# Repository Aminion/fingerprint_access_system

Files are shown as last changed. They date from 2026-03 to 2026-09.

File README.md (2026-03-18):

# Fingerprint Access System





## Project Overview

This project implements a complete biometric access control. It handles asynchronous UART communication for fingerprint authentication, ADC measurements for battery diagnostics, and PWM control for physical actuation. The firmware is written entirely in `no_std` Rust, utilizing the Embassy framework for concurrent, event-driven execution without the overhead of a traditional RTOS.

### Core Capabilities
* **Biometric Authentication:** Secure, asynchronous UART communication with a fingerprint module for user enrollment and verification.
* **PWM-Optimized Actuation:** Implementation of a "peak-and-hold" solenoid drive mechanism using Hardware PWM, significantly reducing active power consumption and thermal load.
* **Ratiometric Battery Diagnostics:** A custom ADC measurement strategy utilizing an external TL431 reference to accurately calculate battery capacity, regardless of internal 3.3V rail voltage sag.
* **Zero-State Power Gating:** Physical isolation of analog subsystems (voltage dividers, reference chips) via GPIO-controlled switching, ensuring 0mA draw from these components during system standby.

## Software Stack & Hardware Architecture

### Software
* **Language:** Rust (`no_std`)
* **Framework:** Embassy (Embedded Async)
* **Concurrency Model:** `embassy-executor` for lightweight task scheduling and interrupt management.

### Hardware & Peripherals
* **Microcontroller:** STM32G031K8 (Nucleo-32)
* **Sensor:** GROW R503
* **Power Supply:** 4xAAA NiMH Battery Pack (~4.0V - 6.0V)
* **Peripheral Utilization:**
  * **PWM (Pulse Width Modulation):** Configured to manage the solenoid's current draw, as well as generate user-feedback tones.
  * **ADC (Analog-to-Digital Converter):** Utilizes extended sample timing (`Cycles160_5`) and floating-point calibration math to bypass hardware limitations.
  * **UART (Universal Asynchronous Receiver-Transmitter):** Handles packet-based serial data transfer with the biometric sensor.
  * **GPIO:** Configured for push-pull power switching and standard digital I/O.

## Engineering Challenges Solved

### 1. Solenoid Power Optimization (Peak-and-Hold)
Solenoids require a high initial "pull-in" current to overcome mechanical inertia, but require significantly less current to maintain the unlocked state. Driving a solenoid at 100% duty cycle for the duration of the unlock period wastes battery capacity and generates excess heat.
* **Solution:** The firmware utilizes hardware PWM to drive the actuating transistor. It applies a 100% duty cycle for the initial actuation phase (e.g., 100ms), then instantly drops the duty cycle to a calculated holding percentage (e.g., 30%). This reduces the holding power consumption by up to 70% while keeping the lock disengaged.

### 2. Ratiometric ADC Calibration
On low pin-count STM32 microcontrollers, the analog reference pin (`AREF`) is internally bonded to `VDDA`. Consequently, when the main 3.3V rail sags under load, the ADC reference shifts, causing inaccurate battery readings.
* **Solution:** A TL431 (2.495V) precision external reference was introduced to a standard ADC channel. The firmware samples both the unknown battery voltage and the known TL431 voltage concurrently. By dynamically calculating the deviation of the TL431 reading, the software mathematically reconstructs the true scale of the 3.3V rail, resulting in a highly accurate battery percentage regardless of system load.

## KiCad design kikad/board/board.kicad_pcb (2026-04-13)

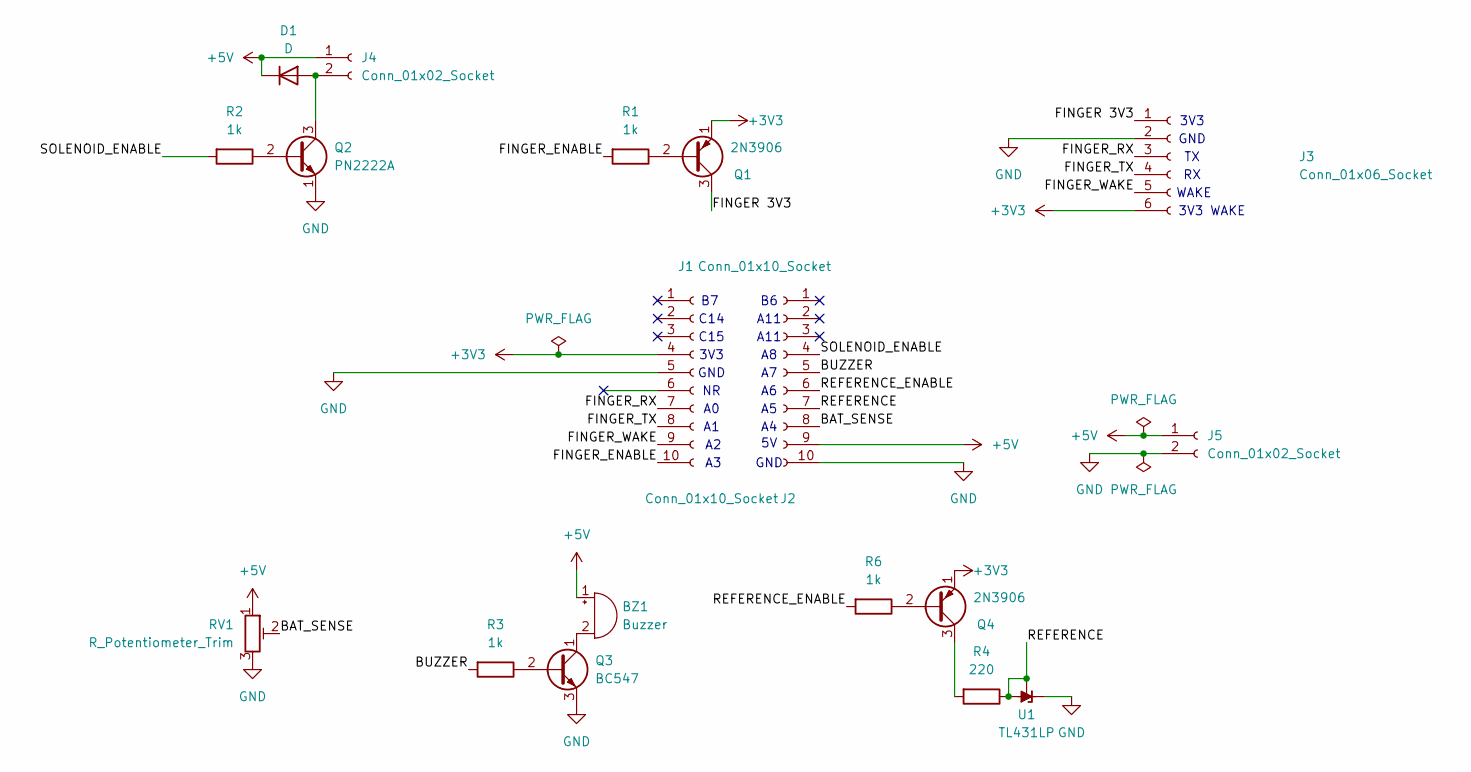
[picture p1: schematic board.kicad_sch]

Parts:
BZ1: Buzzer; Buzzer_12x9.5RM7.6
D1: D; D_DO-41_SOD81_P10.16mm_Horizontal
J1: Conn_01x10_Socket; PinSocket_1x10_P2.54mm_Vertical
J2: Conn_01x10_Socket
J3: Conn_01x06_Socket; JST_XH_B6B-XH-A_1x06_P2.50mm_Vertical
J4, J5: Conn_01x02_Socket; JST_XH_B2B-XH-A_1x02_P2.50mm_Vertical
Q1, Q4: 2N3906; TO-92_Inline_Wide
Q2: PN2222A; TO-92_Inline_Wide
Q3: BC547; TO-92_Inline_Wide
R1, R2, R3, R6: 1k; R_Axial_DIN0207_L6.3mm_D2.5mm_P10.16mm_Horizontal
R4: 220; R_Axial_DIN0207_L6.3mm_D2.5mm_P10.16mm_Horizontal
RV1: R_Potentiometer_Trim; Potentiometer_Runtron_RM-065_Vertical
U1: TL431LP; TO-92_Inline_Wide

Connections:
+3V3: J1.4, J3.6, Q1.1 (E), Q4.1 (E)
+5V: BZ1.1 (+), D1.1 (K), J2.9, J4.1, J5.1, RV1.1
/BAT_SENSE: J2.8, RV1.2
/BUZZER: J2.5, R3.2
/FINGER 3V3: J3.1, Q1.3 (C)
/FINGER_ENABLE: J1.10, R1.2
/FINGER_RX: J1.7, J3.3
/FINGER_TX: J1.8, J3.4
/FINGER_WAKE: J1.9, J3.5
/REFERENCE: J2.7, R4.1, U1.1 (REF), U1.2 (A)
/REFERENCE_ENABLE: J2.6, R6.2
/SOLENOID_ENABLE: J2.4, R2.2
GND: J1.5, J2.10, J3.2, J5.2, Q2.1 (E), Q3.3 (E), RV1.3, U1.3 (K)
unnamed: BZ1.2 (-), Q3.1 (C)
unnamed: D1.2 (A), J4.2, Q2.3 (C)
unnamed: Q1.2 (B), R1.1
unnamed: Q2.2 (B), R2.1
unnamed: Q3.2 (B), R3.1
unnamed: Q4.2 (B), R6.1
unnamed: Q4.3 (C), R4.2

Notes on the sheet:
C14
C15
3V3
GND
WAKE
3V3 WAKE
A11

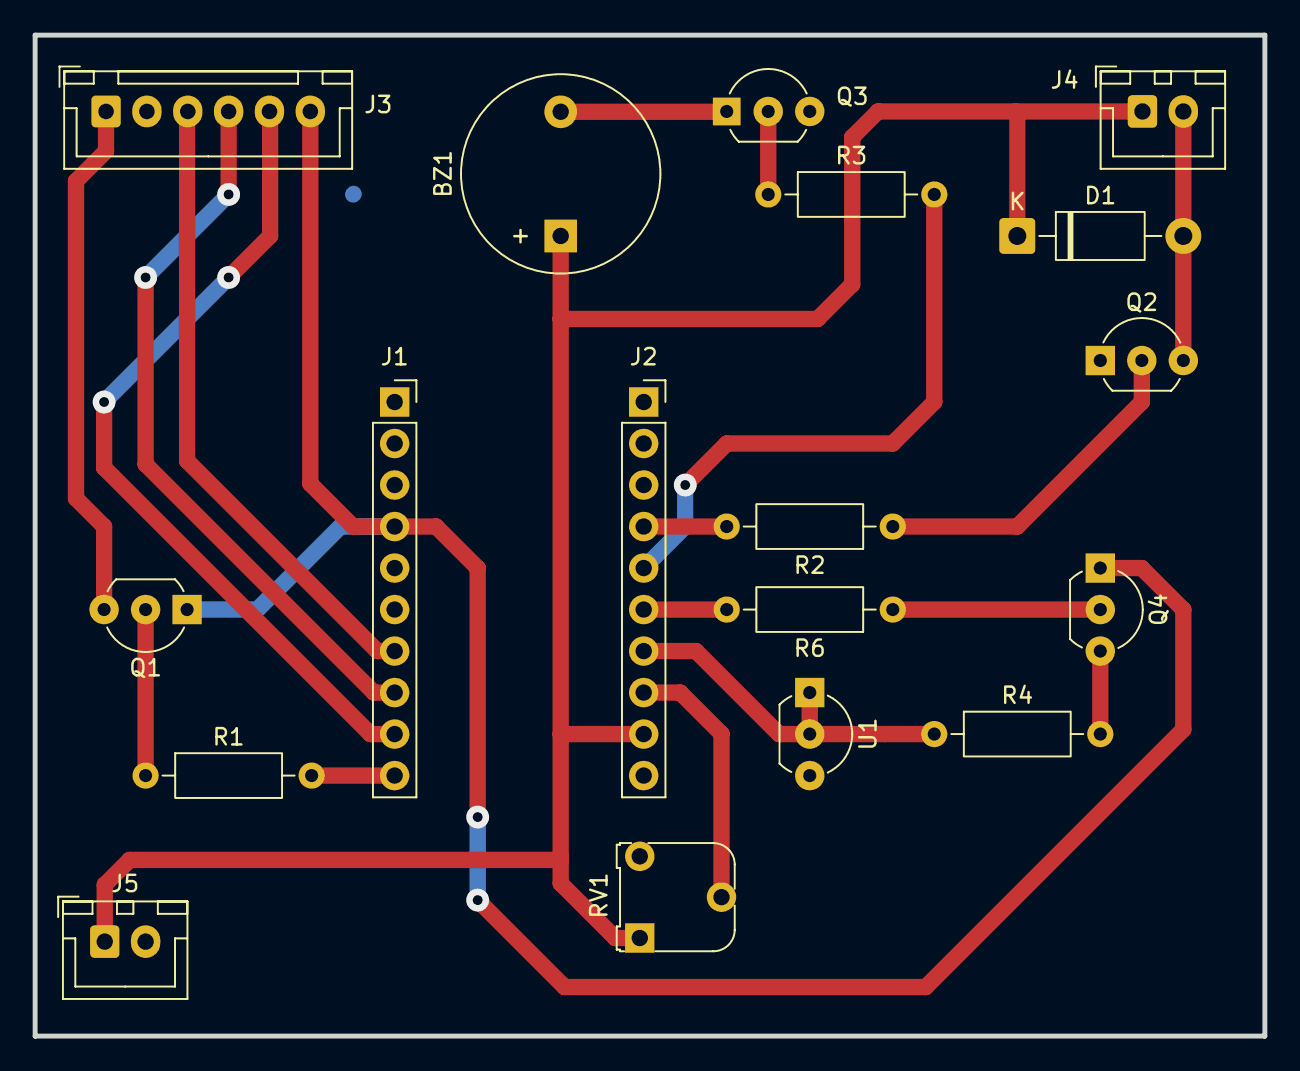
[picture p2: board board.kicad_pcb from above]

Board: 2 copper layers, 75.2 x 61.2 mm, 18 parts (0 on the bottom side), 20 nets.

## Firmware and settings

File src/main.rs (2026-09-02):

#![no_std]
#![no_main]
#![feature(generic_const_exprs)]
#![feature(impl_trait_in_assoc_type)]
#![allow(incomplete_features)]

use embassy_executor::Spawner;
use embassy_stm32 as _;
use embassy_stm32::adc::Adc;
use embassy_stm32::exti::ExtiInput;
use embassy_stm32::gpio::{Level, Output, Pull, Speed, OutputType};
use embassy_stm32::time::{khz, Hertz};
use embassy_stm32::timer::simple_pwm::{PwmPin, SimplePwm};
use embassy_stm32::usart::Uart;
use {defmt_rtt as _, panic_probe as _};

use crate::fingerprint_irq_task::FINGERPRINT_IRQ_STATUS;
use crate::fingerprint_sensor::Irqs;
mod battery_monitoring_task;
mod beeper_task;
mod fingerprint_irq_task;
mod fingerprint_sensor;
mod fingerprint_task;
mod unlock_task;

use battery_monitoring_task::battery_monitor_task;
use beeper_task::beeper_task ;
use fingerprint_irq_task::fingerprint_irq_task;
use fingerprint_task::fingerprint_manager_task;
use unlock_task::unlock_task;

pub type FingerprintSensor = fingerprint_sensor::FingerprintSensor<'static>;

const SENSOR_ADDRESS: [u8; 4] = [0xFF, 0xFF, 0xFF, 0xFF];
const SENSOR_PASSWORD: [u8; 4] = [0x00, 0x00, 0x00, 0x00];
const SENSOR_BAUDRATE: u32 = 57600;
const SOLENOID_FREQUENCY: Hertz = khz(10);

#[embassy_executor::main]
async fn main(spawner: Spawner) {
    let p = embassy_stm32::init(Default::default());

    let button_pin1 = Output::new(p.PA3, Level::High, Speed::Low);

    let mut fingerprint_uart_config = embassy_stm32::usart::Config::default();
    fingerprint_uart_config.baudrate = SENSOR_BAUDRATE;

    let fingerprint_uart = Uart::new(
        p.USART1,
        p.PB7,
        p.PB6,
        p.DMA1_CH1,
        p.DMA1_CH2,
        Irqs,
        fingerprint_uart_config,
    )
    .unwrap();

    let sensor = FingerprintSensor::new(
        button_pin1,
        SENSOR_ADDRESS,
        SENSOR_PASSWORD,
        fingerprint_uart,
    );

    FINGERPRINT_IRQ_STATUS.sender().send(false);
    let fingerprint_irq_pin = ExtiInput::new(p.PA2, p.EXTI2, Pull::Up, Irqs);
    spawner.spawn(fingerprint_manager_task(sensor).unwrap());
    spawner.spawn(fingerprint_irq_task(fingerprint_irq_pin).unwrap());
    let solenoid_pin = SimplePwm::new(
        p.TIM1,
        Some(PwmPin::new(p.PA8, OutputType::PushPull)), // PA8 is Channel 1
        None,
        None,
        None,
        SOLENOID_FREQUENCY,
        Default::default(),
    );

    spawner.spawn(unlock_task(solenoid_pin).unwrap());

    let adc = Adc::new(p.ADC1);
    let beeper_pwm = SimplePwm::new(
        p.TIM14,
        Some(PwmPin::new(p.PA7, OutputType::PushPull)),
        None,
        None,
        None,
        khz(2),
        Default::default(),
    );

    spawner.spawn(beeper_task(beeper_pwm).unwrap());

    let shutdown_pin = Output::new(p.PA5, Level::Low, Speed::Low);
    spawner.spawn(battery_monitor_task(adc, p.PA4, shutdown_pin).unwrap());

    // Park forever without occupying a timer-queue slot.
    core::future::pending::<()>().await;
}

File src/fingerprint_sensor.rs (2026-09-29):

use embassy_stm32::{
    bind_interrupts, dma, exti,
    gpio::Output,
    usart::{InterruptHandler, Uart},
};
use embassy_stm32::mode::Async;
use embassy_time::{with_timeout, Duration, Timer};
use num_enum::TryFromPrimitive;

/// Standard start code for all R503 packets (High byte: 0xEF, Low byte: 0x01)
pub const START_CODE: u16 = 0xEF01;
const POWER_UP_BYTE: u8 = 0x55;
const ENABLE_TIMEOUT: Duration = Duration::from_millis(2000);
const PACKET_TIMEOUT: Duration = Duration::from_millis(1000);

#[repr(u8)]
#[derive(Debug, Clone, Copy, PartialEq, Eq, TryFromPrimitive)]
pub enum Instruction {
    /// Collect finger image and store in ImageBuffer.
    /// Problem: Returns NoFinger if sensor is empty.
    GenImg = 0x01,
    /// Generate character file from image and store in CharBuffer1/2.
    /// Problem: Returns ImageMessy if the scan quality is poor.
    Img2Tz = 0x02,
    /// Precisely compare templates in CharBuffer1 and CharBuffer2.
    /// Problem: Returns NoMatch if the two scans differ.
    Match = 0x03,
    /// Search the library for a template matching CharBuffer1/2.
    /// Problem: Returns NotFound if no match exists in Flash.
    Search = 0x04,
    /// Combine multiple character files into a single template.
    /// Problem: Returns EnrollMismatch if scans were inconsistent.
    RegModel = 0x05,
    /// Store a template from CharBuffer into a specific Flash location.
    /// Problem: Returns BadLocation if ID is out of bounds.
    Store = 0x06,
    /// Set a system parameter (e.g. baud rate index, security level).
    SetSysParam = 0x0E,
    /// Verify the 4-byte system password.
    /// Problem: Required before most other commands can run.
    VfyPwd = 0x13,
    /// Configure the LED indicator (color, speed, mode).
    /// Problem: Returns InvalidReg if parameters are out of range.
    AuraConfig = 0x35,
}

#[repr(u8)]
#[derive(Debug, Clone, Copy, PartialEq, Eq, TryFromPrimitive, defmt::Format)]

pub enum PacketType {
    /// Command packet sent by the MCU.
    Command = 0x01,
    /// Data packet containing image or template bytes.
    Data = 0x02,
    /// Response packet sent by the sensor after a command.
    Acknowledgement = 0x07,
    /// The final packet in a multi-packet data stream.
    EndData = 0x08,
}

#[repr(u8)]
#[derive(Debug, Clone, Copy, PartialEq, Eq, TryFromPrimitive, defmt::Format)]
pub enum ConfirmationCode {
    /// Command executed successfully.
    Ok = 0x00,
    /// Packet was corrupted during transmission (checksum mismatch).
    PacketReceiveErr = 0x01,
    /// No finger detected on the sensor surface.
    NoFinger = 0x02,
    /// Failed to capture image (dirty sensor or dry skin).
    ImageFail = 0x03,
    /// Image is too "noisy" or blurry to process.
    ImageMessy = 0x06,
    /// Image lacks enough distinct ridge features.
    FeatureFail = 0x07,
    /// The two fingerprints compared do not match.
    NoMatch = 0x08,
    /// Scanned finger was not found in the database.
    NotFound = 0x09,
    /// Multiple enrollment scans were too different to merge.
    EnrollMismatch = 0x0A,
    /// The requested Flash Page ID is outside the valid range.
    BadLocation = 0x0B,
    /// Error accessing the fingerprint library (Flash read error).
    DbRangeFail = 0x0C,
    /// Data transfer error during feature upload.
    UploadFeatureFail = 0x0D,
    /// Sensor is busy or failed to respond to the data flow.
    PacketResponseFail = 0x0E,
    /// Error uploading the raw image to the MCU.
    UploadFail = 0x0F,
    /// Failed to delete the requested fingerprint template.
    DeleteFail = 0x10,
    /// Failed to clear the entire fingerprint database.
    DbClearFail = 0x11,
    /// Incorrect 4-byte password provided.
    PasswordFail = 0x13,
    /// No valid image found in the primary buffer.
    InvalidImage = 0x15,
    /// Internal Flash writing error (hardware wear/failure).
    FlashErr = 0x18,
    /// Invalid register number or system parameter.
    InvalidReg = 0x1A,
    /// Correct Address Code received.
    AddrCode = 0x20,
    /// Password verification is required before this operation.
    PassVerifyRequired = 0x21,
    /// Handshake success / Sensor is ready.
    ModuleOk = 0x55,
    /// Undefined response code from hardware.
    Unknown = 0xFF,
}

#[derive(Debug)]
pub enum FingerError {
    /// Hardware/communication error (timeout, framing, overrun).
    Uart(embassy_stm32::usart::Error),

    /// Protocol error (invalid header or checksum mismatch).
    Protocol(&'static str),

    /// Sensor returned a non-Ok confirmation code.
    Sensor(ConfirmationCode),

    /// Received an unexpected packet type (e.g. Data when expecting Ack).
    UnexpectedPacket(PacketType),

    NoFinger,
    NoMatch,
    Timeout,
}

#[repr(u8)]
#[derive(Debug, Clone, Copy, PartialEq, Eq, TryFromPrimitive)]
pub enum LedMode {
    Breathing = 0x01,
    Flashing = 0x02,
    AlwaysOn = 0x03,
    AlwaysOff = 0x04,
    GradualOn = 0x05,
    GradualOff = 0x06,
}

#[repr(u8)]
#[derive(Debug, Clone, Copy, PartialEq, Eq, TryFromPrimitive)]
pub enum LedColor {
    Red = 0x01,
    Blue = 0x02,
    Purple = 0x03,
}

#[derive(Debug, Clone, Copy, PartialEq, Eq)]
pub struct LedEffect {
    pub mode: LedMode,
    pub speed: u8,
    pub color: LedColor,
    pub cycles: u8,
}

impl LedEffect {
    /// How long the animation runs, so a caller can wait it out without
    /// holding a sensor-command guard across the idle time.
    /// Zero for effects that hold a steady level (cycles == 0).
    pub const fn wait_ms(&self) -> u64 {
        if self.cycles == 0 {
            0
        } else {
            (self.speed as u64 * self.cycles as u64 * 32) + 100
        }
    }
}

pub struct Response<const N: usize> {
    pub address: [u8; 4],
    pub packet_type: PacketType,
    pub length: u16,
    pub data: [u8; N],
    pub checksum: u16,
}

/// Implementation to allow embassy's UART error to be automatically
/// converted into FingerError when using the '?' operator.
impl From<embassy_stm32::usart::Error> for FingerError {
    fn from(err: embassy_stm32::usart::Error) -> Self {
        FingerError::Uart(err)
    }
}

pub struct FingerprintSensor<'a> {
    enable_pin: Output<'a>,
    uart: Uart<'a, Async>,
    address: [u8; 4],
    password: [u8; 4],
}

bind_interrupts!(pub struct Irqs {
    USART1 => InterruptHandler<embassy_stm32::peripherals::USART1>;
    DMA1_CHANNEL1 => dma::InterruptHandler<embassy_stm32::peripherals::DMA1_CH1>;
    DMA1_CHANNEL2_3 => dma::InterruptHandler<embassy_stm32::peripherals::DMA1_CH2>;
    EXTI2_3 => exti::InterruptHandler<embassy_stm32::interrupt::typelevel::EXTI2_3>;
});
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

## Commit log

2026-03-02 fingerprint sensore module and his enums
2026-03-08 basic flow
2026-03-10 sensor IRQ handling reworked
    [fingerprint_sensor.rs, main.rs]
2026-03-12 led rework
2026-03-13 uart generalization
2026-03-17 battery monitor
2026-03-18 battery saver
2026-04-10 add kikad scheme
    [board.kicad_pcb, board.kicad_sch]
2026-04-13 fix design
    [board.kicad_pcb]
2026-04-30 add sensor setup
    [board.kicad_sch]
2026-05-04 await 55 byte from sensor
2026-07-03 fix R503 WAKE pin glitch during scan
    The R503 toggles its WAKE pin HIGH mid-scan even with a finger present,
    causing spurious finger-off/on pairs in the IRQ task. Fix with a
    SENSOR_ACTIVE flag (AtomicBool) + RESYNC_SIGNAL: sensor command windows
    are wrapped in a SensorGuard RAII type that sets the flag on entry and
    clears it + triggers a pin re-read on drop. The IRQ task ignores HIGH
    edges while the flag is set and resyncs pin state after each command.
    Also removes the 1000ms workaround delay from finger_on_sensor (no
    longer needed) and reduces the finger-off debounce from 200ms to 50ms
    (capacitive sensor, no mechanical bounce).
    [fingerprint_task.rs]
2026-07-03 audit fixes: timeouts, async cleanup, signal/beeper correctness
    - Add UART read timeouts (2 s enable, 1 s packet) with new FingerError::Timeout
    so a silent sensor can no longer permanently freeze fingerprint_manager_task
    - Remove async from ack_packet — it contained no awaits, wasting state-machine RAM
    - Move EnrollNewUser signal.signal() to after break so caller is only unblocked
    once enrollment truly succeeds, not on the first retry attempt
    - Make BeeperCommand::done optional so battery_monitor can fire-and-forget
    without a dummy static Signal that nobody awaits
    - Fix beeper trailing-delay: inter-beep gap now skipped after the last beep
    - Tighten Watch receiver unwrap() to expect()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
    [battery_monitoring_task.rs, beeper_task.rs, fingerprint_sensor.rs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]
2026-07-03 R503 protocol hardening, datasheet, and sensor layer refactor
    - Fix copy_from_slice panic on short error responses (rejected scan path)
    - Add checksum verification on all received packets
    - Fix search_database error mapping: NotFound(0x09) not NoFinger(0x02)
    - Guard against length_field < 2 underflow; wrong error type on bad length
    - Extract send_command<N> helper; collapse 6 repeated send/recv/ack blocks
    - Replace magic instruction bytes with Instruction enum variants throughout
    - Remove spurious 500ms delay in new() (sensor not powered at that point)
    - Add docs/R503_datasheet.pdf
    [fingerprint_sensor.rs, main.rs]
2026-07-03 audit fixes: ratiometric battery correction, soft-float PWM, unused imports
    - battery_monitoring_task: replace additive correction (u16 underflow risk)
    with ratiometric scaling; add ref_sample==0 guard
    - unlock_task: replace f32 duty cycle math with set_duty_cycle_fully_on /
    set_duty_cycle_fraction(3,4) — no soft-float on M0+
    - remove unused `use core::u64` from main.rs and unlock_task.rs
    [battery_monitoring_task.rs, main.rs, unlock_task.rs]
2026-07-03 fix battery alert: swap signals so critical voltage triggers urgent beep
    [battery_monitoring_task.rs]
2026-07-03 generic transact API; tolerate RX residue during sensor power-up
    - add transact<REQ, RESP> as the single write/receive/ack pipeline;
    send_command and search_database are now thin wrappers over it
    - enable(): discard UART errors and garbage bytes while hunting for the
    0x55 handshake — the unpowered sensor holds RX low, latching a framing
    error that previously aborted enable() on the first read
    [fingerprint_sensor.rs]
2026-07-03 fix resync race: skip pin publish if a new sensor command window opened
    RESYNC_SIGNAL fires on every guard drop, but a new guard can be created
    before the IRQ task handles it. The 10ms settle then overlapped the next
    command window, reading a glitching WAKE pin and publishing spurious
    finger state. Re-check SENSOR_ACTIVE after the settle; the active
    window's own guard drop re-fires the resync.
2026-07-03 api/math cleanup: to_be_bytes, inferred const args, pending() park
    - replace split_to_bytes and START_CODE_H/L with u16::to_be_bytes
    - unify compute_checksum on wrapping_add
    - infer payload length at transact call sites (generic_arg_infer is
    stable since 1.89)
    - park main with core::future::pending instead of a 136-year timer
    [fingerprint_sensor.rs, main.rs]
2026-07-13 beeper PWM on TIM14/PA7; battery task on PA4; defmt log level; cleanup
    - beeper_task: switch from GPIO toggle to hardware PWM (TIM14 CH1, PA7, 2 kHz)
    - main: spawn beeper and battery tasks before pending(); add startup beep
    - battery_monitoring_task: measure PA4 directly, drop ratiometric reference
    circuit; add defmt voltage print
    - .cargo/config.toml: set DEFMT_LOG=trace so probe-rs shows output
    - fingerprint_sensor: remove dead create_verify_packet; tighten FingerError docs
    - fingerprint_task: remove unused embassy_stm32 import
    [battery_monitoring_task.rs, beeper_task.rs, fingerprint_sensor.rs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]
2026-07-13 battery_monitoring_task: remove voltage debug print
2026-07-14 remove RANGE2 voltage scaling; clean up debug logging
    RANGE2 (VCore ~1.0V) breaks UART DMA RX even at 16 MHz — enable()
    times out and all sensor communication fails. Reverted to default
    VCore (RANGE1). Also removed leftover debug println! calls added
    during the baud-rate and wire-break investigation.
    [battery_monitoring_task.rs, fingerprint_task.rs, main.rs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]
2026-09-02 fix release build: opt-level z triggers unimplemented AAPCS intrinsics; pin toolchain
    At opt-level='z' the thumbv6m release build fails to link: LLVM lowers
    unaligned 4/8-byte moves (Response<N>/Result through the async task state
    machines) into calls to __aeabi_uread4/uwrite4/uread8/uwrite8, which
    compiler_builtins does not implement (verified against 0.1.160 source and
    the precompiled sysroot). opt-level='s', '2', and '3' all avoid the path;
    switch release to 's'.
    Also pin shell.nix to a fixed rust-overlay commit and nightly date instead
    of floating on rust-bin.nightly.latest off master.tar.gz, so the toolchain
    can't silently drift into this (or a new) codegen regression again.
2026-09-02 battery: hardware shutdown on critical charge via PA5, add SetSysParam
    PA5 starts low and is driven high once the critical-charge beeper
    warning finishes playing; on this board it cuts MCU power directly, so
    the task intentionally falls through to the next loop iteration rather
    than parking (power is gone before it matters).
    Recalibrated V_FULL from 1.35V/cell to 1.2V/cell to match the sense
    divider, which shifts V_LOW_LEVEL/V_CRITICAL_LEVEL earlier in the
    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
2026-09-29 update Cargo.lock: bump 14 transitive deps, cortex-m-rt 0.7.6 -> 0.7.7
    Semver-compatible refresh only; Cargo.toml is unchanged. Checked every
    direct dependency against the crates.io sparse index: embassy-stm32 0.6.0,
    embassy-executor 0.10.0, embassy-time 0.5.1, embassy-sync 0.8.0, defmt
    1.1.1 and num_enum 0.7.6 are already the newest published releases, so
    there is no major bump or embassy migration outstanding.
    Note that `cargo info` run inside the workspace reports the locked version
    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
2026-09-29 validation: retry while the finger stays on the sensor, fix lost re-press
    Recognition was single-shot: one bad scan (NoMatch, ImageMessy, FeatureFail)
    gave up immediately. Retry up to MAX_VALIDATE_ATTEMPTS with a delay between
    attempts, stopping early when the finger is lifted.
    The stop condition comes from the sensor, not the WAKE pin: GenImg answers
    Sensor(ConfirmationCode::NoFinger) once the finger is gone. FINGERPRINT_IRQ_STATUS
    cannot serve here — SENSOR_ACTIVE suppresses the pin's HIGH edges for the whole
    command window by design, so right after a failed scan the watch still reads
    true whether or not a finger is present, and its resync only sends on a change,
    so a still-present fing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
    [fingerprint_sensor.rs, fingerprint_task.rs]
2026-10-12 battery: compensate VDDA drift using factory-calibrated VREFINT
    VREF+ is bonded to VDD on LQFP32, so the ADC full scale follows the 3V3
    rail. Measure VDDA against VREFINT each cycle and compare the battery
    voltage in mV instead of raw counts that assumed exactly 3.3 V.
2026-10-12 bump nightly to 2026-10-12 (rustc 1.101.0, LLVM 23.1.3)
    The new nightly's compiler_builtins provides __aeabi_uread4/uwrite4/
    uread8/uwrite8, so release at opt-level='z' links again on thumbv6m.
    'z' is ~1.4 KB larger than 's' for this firmware, so the release
    profile stays on 's'. rust-overlay pin moved to 404b7a5 to include it.
2026-10-15 battery: fix divider scaling, average 16 samples, single-step u64 math
    The voltage was scaled with the nominal 4x1.2 V pack voltage as the
    3.3 V-on-pin point, but RV1 is trimmed so 5.5 V gives 3.2 V. Scale with
    the actual calibration point instead.
    Sum 16 interleaved VREFINT/BAT_SENSE readings to reduce noise near the
    thresholds, and compute the result in one u64 division so intermediate
    steps are not truncated.
2026-10-20 enroll: store into lowest free library slot via ReadIndexTable
    Enrolment always wrote slot 1, so each new finger overwrote the last.
    Read the sensor's occupancy bitmap before scanning and store into the
    first empty slot; LibraryFull when all 200 are taken.
2026-10-20 sensor: typed Command trait, closure-based command windows
    - Each sensor instruction is a struct implementing `Command` (instruction,
    params, reply decoding, error mapping); one generic `run()` replaces
    transact/send_command and the per-command methods. LedEffect is a command.
    - Packets use fixed buffers, dropping generic_const_exprs.
    - Short or empty acknowledgements are now protocol errors instead of being
    zero-padded (a short ReadIndexTable could report occupied slots as free).
    - Command windows go through `sensor.window(async |s| ...)`; the manager
    task is split into validate_access / scan_and_match / enroll.
    - create_model + store_template share one window.
    - Log the matched slo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
2026-10-20 generic request/reply helper, Watch::get_and, Duration everywhere
    - request.rs: `Reply<T>` alias and `request()` (send a command carrying
    its reply signal, wait for the result). Used by unlock_task,
    add_new_finger_task and the critical-battery shutdown beep.
    - finger_on_sensor uses Watch receiver get_and instead of a manual loop.
    - Delays are `Duration` throughout: LedEffect::duration(),
    VALIDATE_RETRY_DELAY, solenoid KICK/HOLD, IRQ DEBOUNCE/SETTLE.
2026-10-21 fingerprint: presence via GenImg, WAKE only for the press
    WAKE toggles on its own while the R503 is powered, which caused a
    second recognition with the finger held and false lifts in enroll.
    The manager now owns the WAKE pin and only arms it (high, then low)
    while the sensor is off; while powered, presence comes from GenImg
    (capture / wait_lift), and every flow ends with the finger off.
    Removes the irq task, SENSOR_ACTIVE, command windows, resync and
    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
2026-10-21 pwm: pull-down on solenoid and buzzer pins
    A disabled timer channel stops driving its pin, leaving the driver
    transistor's base floating between unlocks/beeps. Also drop pin speed
    to Low; 2-10 kHz doesn't need VeryHigh edges.
